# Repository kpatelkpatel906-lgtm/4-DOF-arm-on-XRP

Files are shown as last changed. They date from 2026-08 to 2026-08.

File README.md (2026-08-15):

(V2) 4 Degrees of Freedom Robotic Arm on Custom robot base powered by XRP
-----------------------------------------------------------------------------------------------------------------------------------------------------------------------------------------------------
Screenshot 2026-07-31 at 10 17 01 PM

About - This project was created during Hack Club's Macondo program. It uses a custom made chassis and adds onto it by using 4 MG995 servo motors and various different 3d printed objects to make a 4 degree of freedom robotic arm ontop of the robot. Throughout the next couple months, there will be many updates/upgrades to the software used to control the robot and will likely use a bluetooth webtool that is unique (but will first start using something like pestol.ink) and there will be updates to the hardware used (ex: custom board, new grabbing mechanisms, different chassis look, etc.)
-----------------------------------------------------------------------------------------------------------------------------------------------------------------------------------------------------
Helpful links
-------------
**XRP Code Editor - https://xrpcode.wpi.edu**

OnShape CAD (full V2) **(DISCLAIMER - the CAD model for the XRP wheel and the motor were not created by me)**- https://cad.onshape.com/documents/8c0d30bc27f93aca9cecb3c5/w/34c3822477bc31986b632ba4/e/a49cac85e221fc7f59d26fd0
OnShape CAD (V1/V1.5 Claw) - https://cad.onshape.com/documents/94cab965c461ea71e610c3a8/w/6c71823ed011eed3911d8ce7/e/d39e55db9d4270f620e11d48

Orb Game Piece used to test claw (called "Rubble") - https://www.printables.com/model/1251185-2025-xrp-game-orbit-odyssey/files 

Instructions for V2
-------------------
1) Print out all pieces on OnShape file (wheel and wheel retainer and gear and grabber should have 2 of each) with the exception of the XRP motor and XRP included wheel; ideally out of Basic PLA
2) Take the base and the XRP motors with the sensor side being on the lower part of the motor area like picture below
   Screenshot 2026-08-01 at 11 01 27 PM
3) Place the motor retainers onto the top of the motor and line up the holes
4) Screw the retainer onto the drive base using 4 (2 per retainer) M3 6mm buttonhead screws
5) Attach the included wheel to both motors and use the included screw in the XRP kit to secure
6) Take the wheel and insert in onto the pegs on the sides of the robot
7) Take the wheel retainer and place on top of the hole and use 2 M3 4mm screws to secure
   Base should look like so -
   Screenshot 2026-08-06 at 10 49 15 PM
9) Attach the XRP board to the center of the robot base with the barrel-jack connector facing away from the wall using 4 M3 4mm screws using a M3 nut as a standoff between the board and the base
10) Connect the provided XRP battery to the board and plug in the left and right motors to the left and right motor slots on the board
11) Place battery in the area enclosed by the rectangle, should make battery sit at an angle
12) Then assemble the arm battery packs by make 2 sets of 2 2AA battery holders connected in series (Red wire of one connected to the Black of the Other) and then connect the two sets in parallel by connect the reds together and then the blacks together
13) Move these batteries to the area that is also occupied by the barrel-jack connector
14) Then attach the servo platform to the base using 4 M3 25mm socketheads
15) Attach the power rails of a breadboard to either side of the longer part of this servo platform
16) Attach a MG995 motor using 4 M3 4mm screws
17) Attach Servo horn (4 point) using included screw (all other servos need the circular horn)
18) Attach Joint 1 to the the servo horn using included screws where the slot for the motor wires should be facing the front (where the back is the numbers 1208)
19) Press another MG995 into the the square area with motor wire protect on the side of the slot
20) Replace the back plate on the servo for arm support bracket and do so for one more MG995
21) Slide the second joint by first sliding the bracket onto the support bracket and then orient it on the face of the servo horn, secure using included screws
22) Secure the second MG995 motor using 4 M3 6mm screws
23) Secure the third MG995 motor using 4 M3 4mm screws
24) Secure the claw onto the third MG995 by using the same method as the second joint
25) Insert the final motor into the claw shroud in a parallel manner to the arm and secure using 4 M3 4mm screws
26) Attach the two gears pointing forward and secure the one powered using included screws and the one that is static by placing it on the "pin" and then using the gear retainer and 1 M3 4mm screw to retain
27) Attach the claw grabbers were ends should be pointing towards each other and secure to the gears using 4 M3 6mm screws
   Fully assembled claw looks something like this -
   Screenshot 2026-08-06 at 10 54 14 PM

Electronics instructions
------------------------
1) Take 2 2AA battery back holders and connect these two in series
2) Repeat step 1
3) Connect the two pairs of batteries together in series to get a total voltage 4 times that of a standard AA and current that is double that of a standard AA
   
5) Take a power rail of the breadboard and insert 2 300uf 16V capacitors with the small side inside of the negative terminal
6) Then place the female side of a dupont connector and attach to the XRP servo pinout (specifically the signal wire)
7) Then place 4 sets of male to male jumper wires on the negative side
8) Repeat step 6 but for the positive side
9) Connect the negative wires to the brown colored slot on the servo extension wire
10) repeat step 8 but using positive wires and the red colored slot
11) Repeat step 8 but using the dupont connectors from step 5 and connect to the yellow slot on servo extension wires
12) Use enough slack on the cables using the servo extension wires to make sure that nothing gets caught when arm is in motion
13) Note - I would use some electrical tape with the jumper wires to ensure that nothing gets unplugged from random motion on the arm/drivebase

Additional Electronics help
---------------------------
Follow the diagram, servo motor signal wires go to any of the 4 signal wires on the board for the way that you have configured as each motor
Additionally, this diagram doesn't take into account the use of a breadboard; distinct positive and negative lines have been made for a little ease of understanding.
Screenshot 2026-07-29 at 11 29 17 PM

videos 
part 1 - https://youtu.be/mma-man9Brw
part 2 - https://youtube.com/shorts/A3m_HA8ld8k?feature=share

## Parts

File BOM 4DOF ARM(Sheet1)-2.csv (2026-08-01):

Item Name | Price | Price per Unit | Quantity | Total | Link to purchase
XRP Robot Kit | 119.95 | 119.95 | 1 | 119.95 | https://www.sparkfun.com/xrp?gad_source=1&gad_campaignid=17479024030&gbraid=0AAAAADsj4ESfX7tpll5UkmOZUqH8LsG8d
MG995 Servo Motor | 17.98 | 4.495 | 4 | 17.98 | https://www.amazon.com/Deegoo-FPV-Servo-MG995-Metal-Gear/dp/B07NQJ1VZ2?th=1
Inland PLA Filament | 9.99 | 0.00999 | 133.77 | 1.3363623 | https://www.microcenter.com/product/692936/inland-175mm-pla-basic-3d-printer-filament-1kg-(22lbs)-cardboard-spool-white
Servo Wire Extensions | 9.99 | 0.454090909 | 2 | 0.908181818 | https://www.amazon.com/AEDIKO-Extension-Connectors-Connection-Control/dp/B09BPX1HNS
M3 Screw Set | 9.99 | 0.01040625 | 18 | 0.1873125 | https://www.amazon.com/Screwish-Metric-Assortment-Washers-Printing/dp/B0GJRVX7F8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
Double AA batteries | 8.49 | 0.7075 | 4 | 2.83 | https://www.amazon.com/AmazonBasics-Performance-Alkaline-Batteries-12-Pack/dp/B07KWYGTC6
Battery holder | 5.49 | 1.3725 | 4 | 5.49 | https://www.amazon.com/VWEICYY-Battery-Holder-housing-Without/dp/B0GJT9V955
Breadboard power rails | 2.56 | 2.56 | 1 | 2.56 | https://www.digikey.com/en/products/detail/busboard-prototype-systems/BB50R/28714630?gclsrc=aw.ds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
300uf 30V Capacitor | 1.05 | 1.05 | 2 | 2.1 | https://www.digikey.com/en/products/detail/chemi-con/EKYC500ELL301MJ16S/10486467
M to F jumper | 1.95 | 0.0975 | 4 | 0.39 | https://www.digikey.com/en/products/detail/adafruit-industries-llc/1954/6827087?gclsrc=aw.ds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
M to M jumper | 1.95 | 0.0975 | 10 | 0.975 | https://www.adafruit.com/product/1957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
TOTAL |  |  |  | 154.7068566

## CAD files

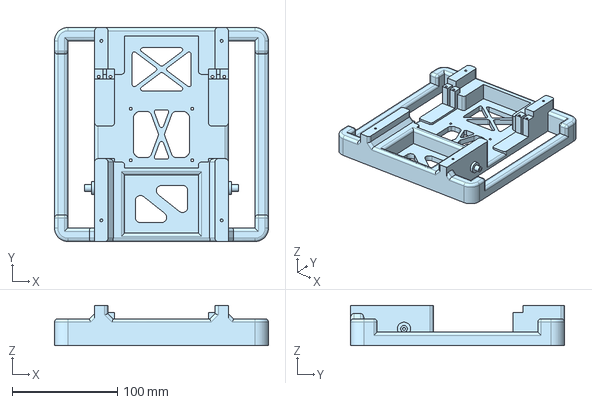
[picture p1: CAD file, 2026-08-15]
ALL STEP/Full Assembly - Main base.step
203.2 x 203.2 x 38.1 mm

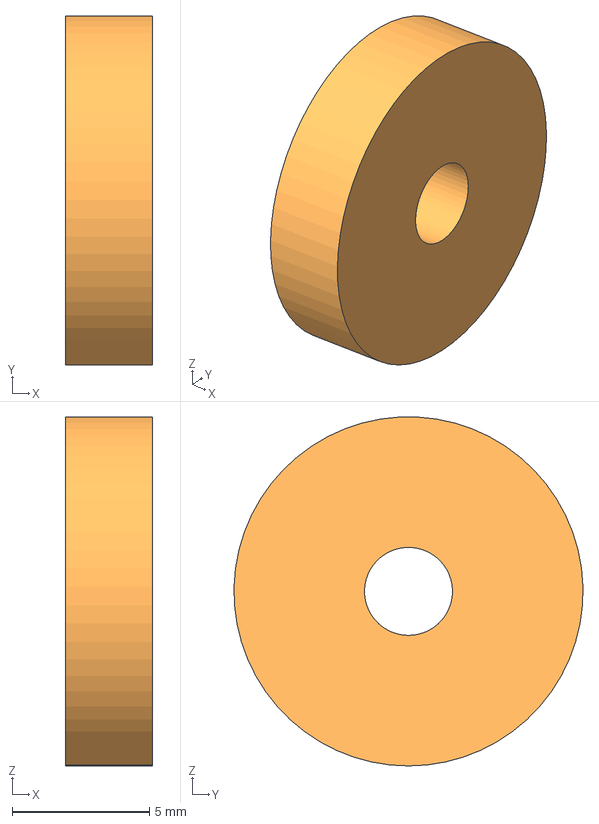
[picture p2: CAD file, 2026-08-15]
ALL STEP/Full Assembly - Retainer for wheel.step
3.17 x 12.7 x 12.7 mm

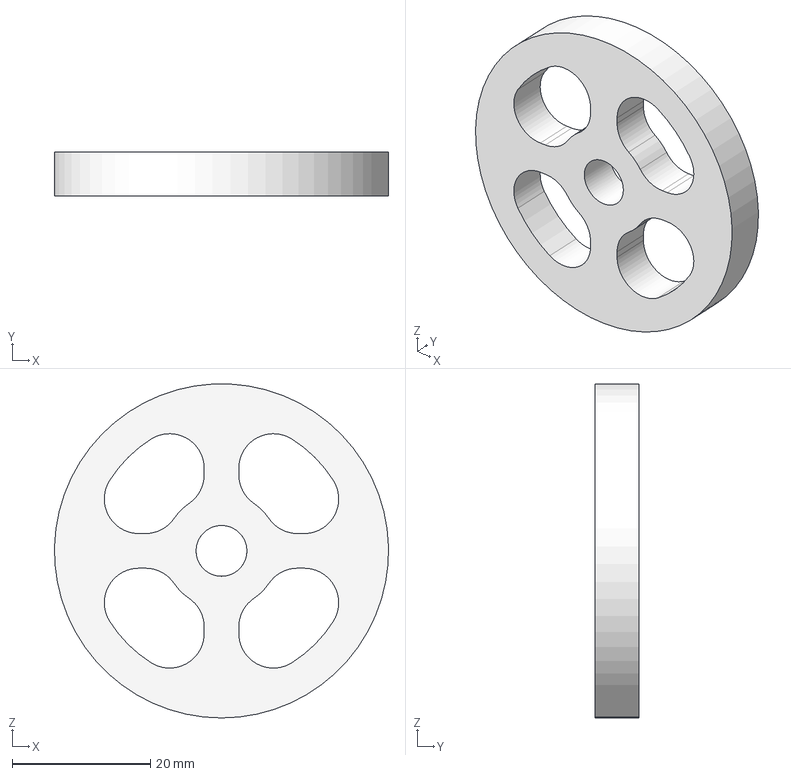
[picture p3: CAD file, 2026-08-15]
ALL STEP/Full Assembly - Support Wheel.step
48.2 x 6.35 x 48.2 mm

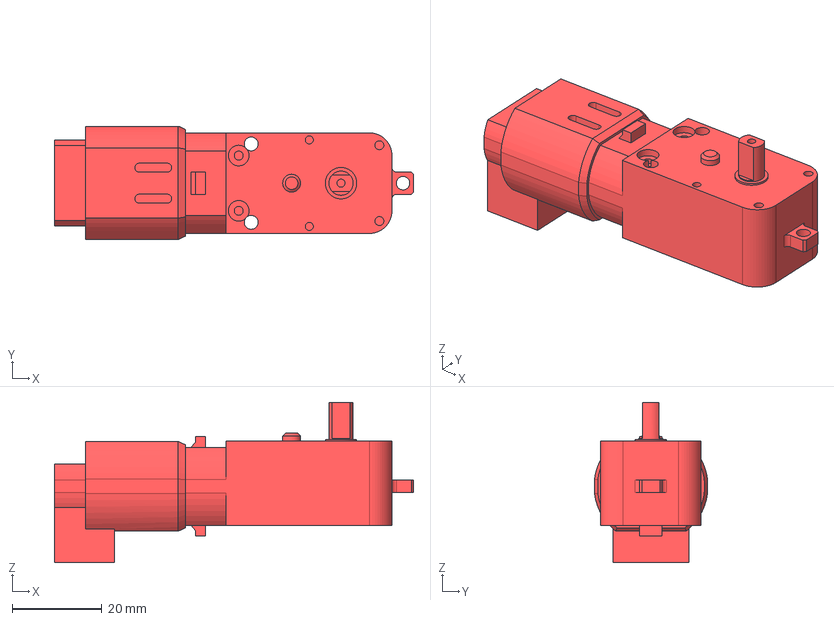
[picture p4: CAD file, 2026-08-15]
ALL STEP/Full Assembly - Part 1.step
79.9 x 25.2 x 35.7 mm

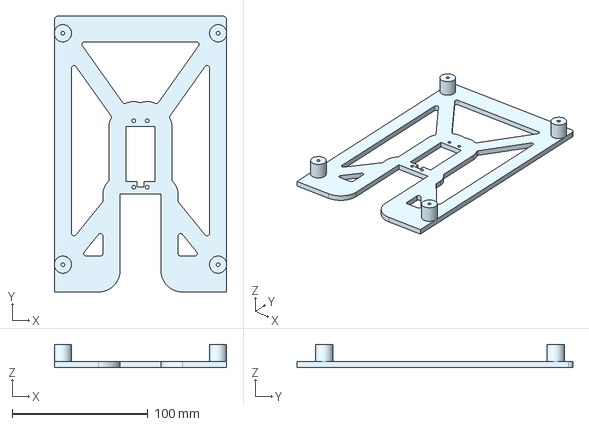
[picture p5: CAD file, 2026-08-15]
ALL STEP/Full Assembly - Main Servo Platform.step
127.0 x 203.2 x 16.9 mm

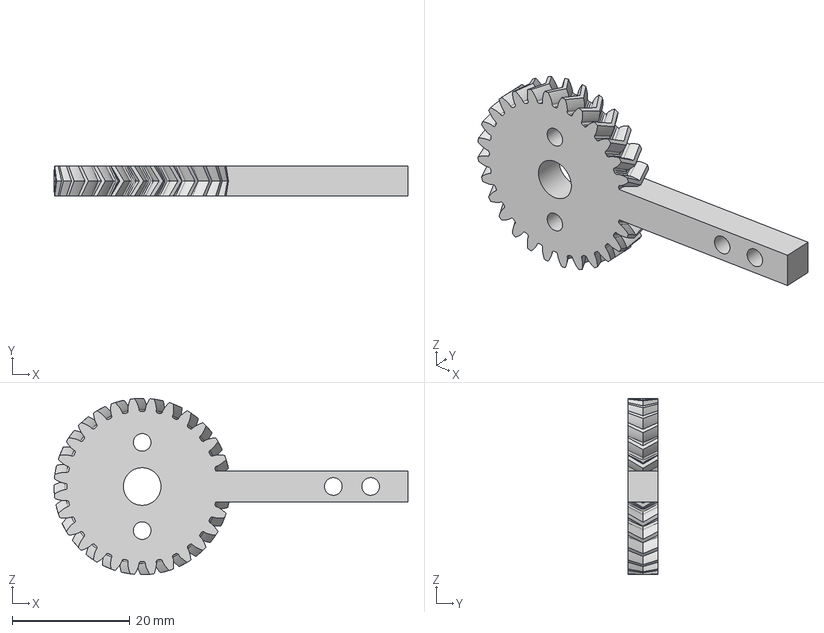
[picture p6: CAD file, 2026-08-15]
ALL STEP/Full Assembly - Spur gear (28 teeth).step
60.2 x 5.08 x 30.0 mm

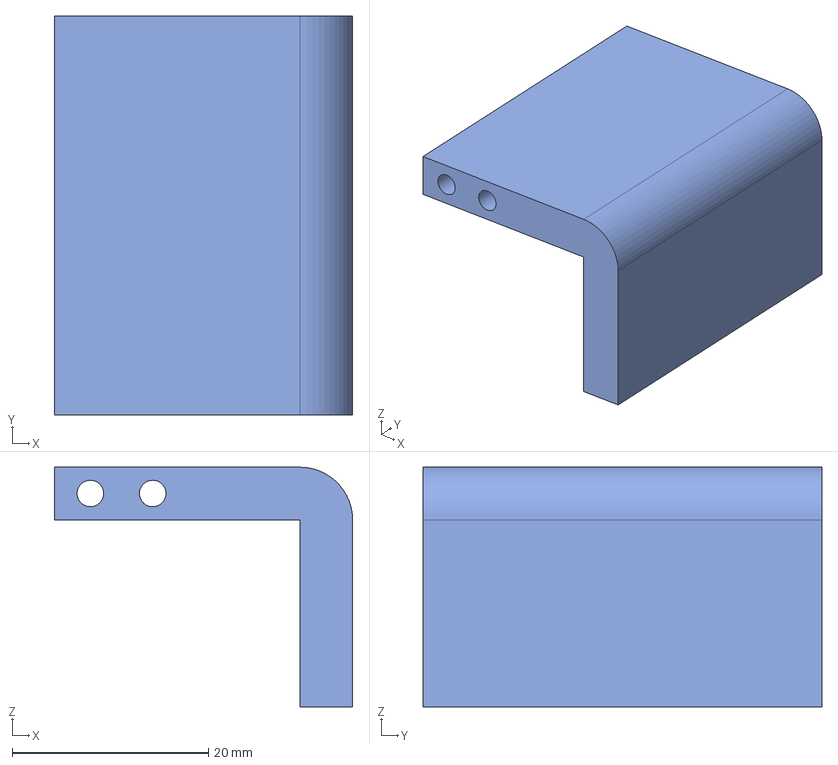
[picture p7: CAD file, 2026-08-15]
ALL STEP/Full Assembly - Part 3.step
30.4 x 40.6 x 24.4 mm

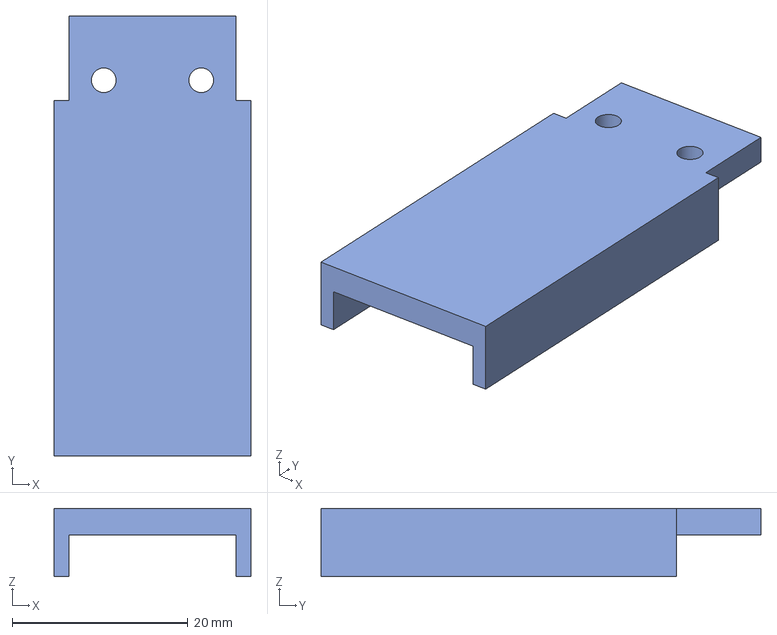
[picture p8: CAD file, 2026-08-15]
ALL STEP/Full Assembly - Motor Retainer.step
22.4 x 50.0 x 7.75 mm

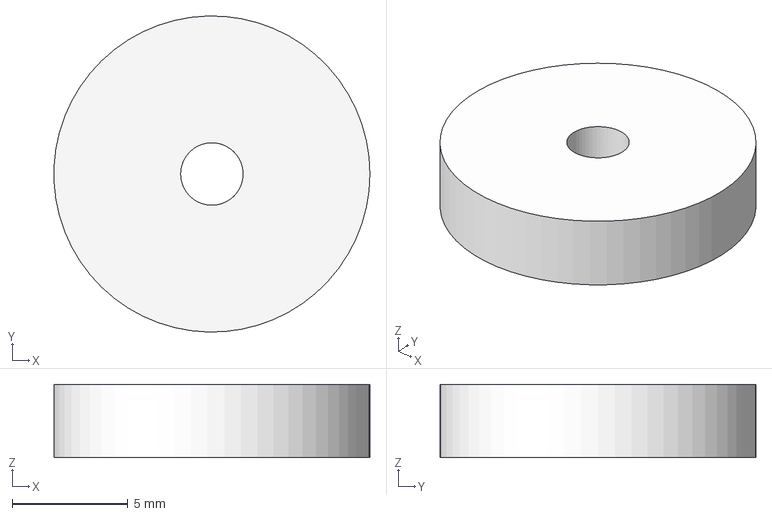
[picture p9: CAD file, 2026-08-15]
ALL STEP/Full Assembly - Part 4.step
13.6 x 13.7 x 3.17 mm

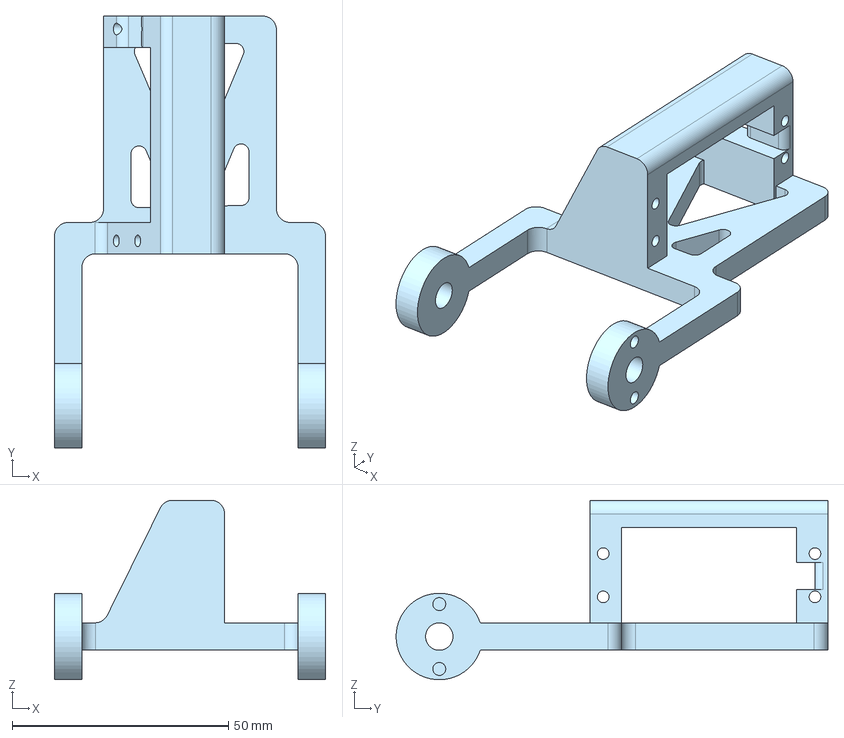
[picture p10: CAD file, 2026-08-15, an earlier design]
ALL STEP/Full Assembly - Part 1 (5).step
62.7 x 99.9 x 41.5 mm

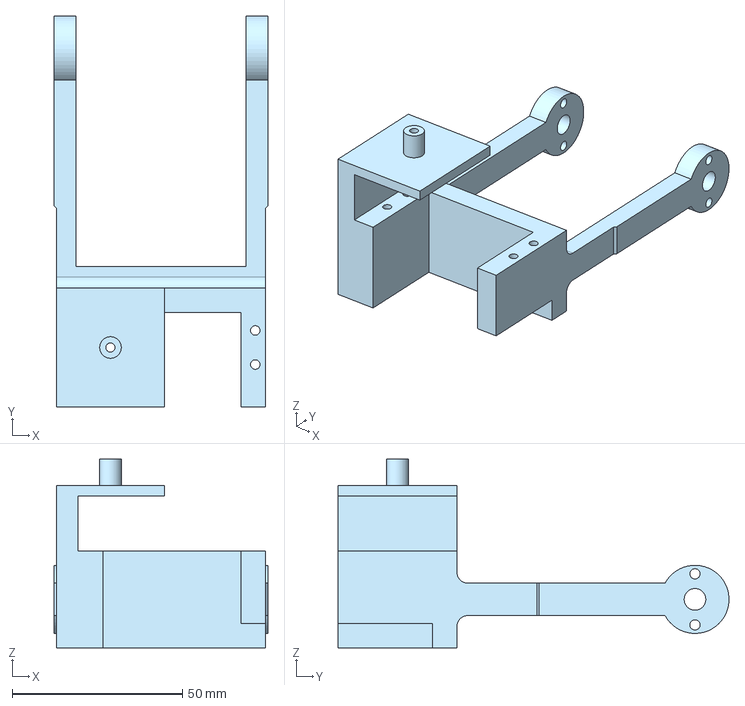
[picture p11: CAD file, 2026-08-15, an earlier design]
ALL STEP/Full Assembly - Part 1 (2).step
62.7 x 114.8 x 55.4 mm

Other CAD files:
ALL STEP/Full Assembly - Part 1 (3).step
ALL STEP/Full Assembly - Part 1 (6).step
ALL STEP/Full Assembly - Part 1 (4).step
ALL STEP/Full Assembly - Spur gear (28 teeth) (1).step
ALL STEP/Full Assembly - Retainer for wheel (1).step
ALL STEP/Full Assembly - Support Wheel (1).step
ALL STEP/Full Assembly - Part 3 (1).step
ALL STEP/Full Assembly - Motor Retainer (1).step
ALL STEP/Full Assembly - Part 1 (1).step

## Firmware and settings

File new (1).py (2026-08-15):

# Import necessary modules
from machine import Pin, ADC
import bluetooth
import time
import math

from XRPLib.defaults import *
from pestolink import PestoLinkAgent


robot_name = "4DOF"

# Create an instance of the PestoLinkAgent class
pestolink = PestoLinkAgent(robot_name)

# Initialize toggle before the loop to prevent NameError
toggle = 0

# Start an infinite loop
while True:
    if pestolink.is_connected():  # Check if a BLE connection is established
        board.set_rgb_led(2, 247, 2)
        rotation = -1 * pestolink.get_axis(0)
        throttle = -1 * pestolink.get_axis(1)

        # Corrected button check chain
        if pestolink.get_button(2):
            toggle = 0
        elif pestolink.get_button(3):
            toggle = 1

        # Mode 0 Logic
        if toggle == 0:
            drivetrain.arcade(throttle, rotation)

            if pestolink.get_button(0):
                servo_four.set_angle(90)
                servo_three.set_angle(90)
                servo_two.set_angle(0)
                servo_one.set_angle(90)
                board.set_rgb_led(2, 2, 247)

            if pestolink.get_button(1):
                servo_four.set_angle(90)
                servo_three.set_angle(180)
                servo_one.set_angle(180)
                board.set_rgb_led(251, 255, 2)

            if pestolink.get_button(6):
                servo_two.set_angle(0)
                board.set_rgb_led(5, 255, 255)

            if pestolink.get_button(7):
                servo_two.set_angle(120)
                board.set_rgb_led(255, 5, 255)

        # Mode 1 Logic
        elif toggle == 1:
            if pestolink.get_button(6):
                servo_two.set_angle(0)
                board.set_rgb_led(5, 255, 255)

            if pestolink.get_button(7):
                servo_two.set_angle(120)
                board.set_rgb_led(255, 5, 255)

            servo_four.set_angle((-1 * pestolink.get_axis(0)) + 90)
            servo_three.set_angle((-1 * pestolink.get_axis(2)) + 90)
            servo_two.set_angle((-1 * pestolink.get_axis(3)) + 90)

        batteryVoltage = (ADC(Pin("BOARD_VIN_MEASURE")).read_u16()) / (
            1024 * 64 / 14
        )
        pestolink.telemetryPrintBatteryVoltage(batteryVoltage)

    else:
        drivetrain.arcade(0, 0)
        board.set_rgb_led(247, 2, 2)
        board.led_on()

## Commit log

2026-06-22 Add note about upcoming assembly information
    Added a note about upcoming assembly information.
2026-06-28 Update README with robot assembly instructions part 1
    Added assembly instructions for the XRP robot base and servo setup.
2026-07-02 Finish servo motor assembly steps in README
    Updated assembly instructions for servo motors and joints.
2026-07-30 Create Old READme for arm
2026-07-30 Revise README for 4DOF Robotic Arm project
    Updated the README to include project details, instructions, and helpful links for the 4 Degrees of Freedom Robotic Arm.
2026-07-30 Fix formatting in Old README for arm
    Updated the README to correct formatting and improve clarity.
2026-08-02 Update README with V2 assembly instructions
    Added detailed instructions for V2 assembly and additional electronics setup.
2026-08-05 Enhance assembly instructions in README
    Added detailed assembly instructions for attaching motors and components to the servo platform.
2026-08-07 Enhance assembly instructions for wheels and electronics
    Added additional assembly steps for attaching wheels and electronics. Updated instructions for connecting battery holders and servo motors.
2026-08-15 Create Wiring Diagram
2026-08-15 Insert image into Wiring Diagram
    Added an image to the wiring diagram.
2026-08-15 all 3d printed items are in these files
    (plus there is onshape too for extra stuff)
2026-08-15 Delete ALL STEP FILES.stl
    ts was an stl file
2026-08-15 Add files via upload
    THIS IS DESIGNED PARTS (minus the servo bc that was not relevant to the design more so external)
    [Full Assembly - Main Servo Platform.step, Full Assembly - Main base.step, Full Assembly - Motor Retainer (1).step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]
2026-11-06 Rename Screenshot 2026-11-06 9.39.14 AM.png to Wiring Diagram
2026-11-06 Rename ALL STL FILES.stl to ALL STEP/STL Files
2026-11-06 new folder name for cad file
2026-11-06 wiring diagram
2026-11-06 Update README with board flashing and known issues
    Added notes about flashing the XRP Board, known issues with AA battery performance, and a reference to the Bill of Materials.
